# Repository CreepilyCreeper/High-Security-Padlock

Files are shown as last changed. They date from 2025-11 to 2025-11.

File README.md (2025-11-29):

# High-Security Padlock Design (EN 12320 Grade 5)

**Project Status:** Completed (Academic Design & Analysis)
**Tools Used:** SolidWorks

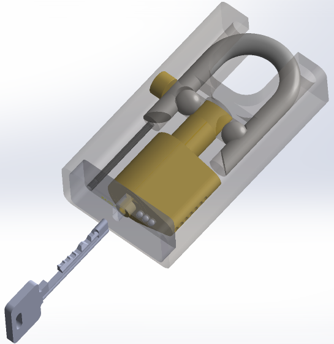
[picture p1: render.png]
Main Render


*(Final assembly render of the modified Bowley-style padlock)*

Animation

*(Animation of padlock mechanism)*

## Abstract
This project involves the design and analysis of a high-security padlock engineered to meet **EN 12320 Grade 5** standards. The design replaces conventional brass bodies with **AISI 304 Steel** and incorporates **Hardened Boron Steel** for the shackle (UTS > 1600 MPa). 

The primary innovation is a modified Bowley-style locking mechanism that shields pin access, rendering traditional lockpicking tools (raking/single-pin picking) ineffective.

## Technical Specifications

| Feature | Specification |
| :--- | :--- |
| **Shackle Material** | Hardened 1.5510 Boron Steel (UTS ≥ 1600 MPa) |
| **Body Material** | AISI 304 Stainless Steel (Machined) |
| **Locking Mechanism** | 7-Pin Modified Bowley System (Shielded Keyway) |
| **Anti-Drill** | Embedded 52100 Chrome Steel Bearings |
| **Key Differs** | > 16,000 combinations ($4^7$) |
| **Est. Production** | CNC Milling & Turning (ISO 286 Grade 8 Tolerances) |

## Engineering Analysis (FEA)

### 1. Shackle Tensile & Torsion Test
Finite Element Analysis verified the shackle withstands tensile forces exceeding **70 kN** and torsion forces exceeding **1200 Nm**.

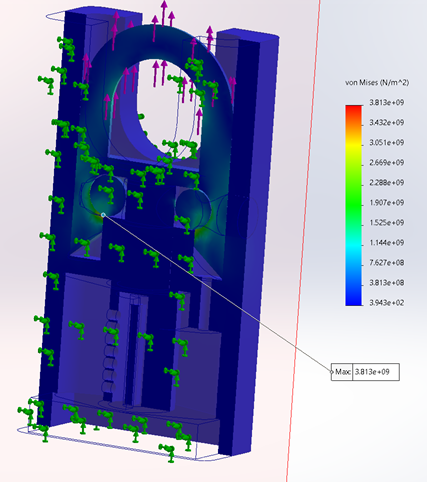
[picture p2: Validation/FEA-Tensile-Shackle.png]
FEA Shackle Tensile
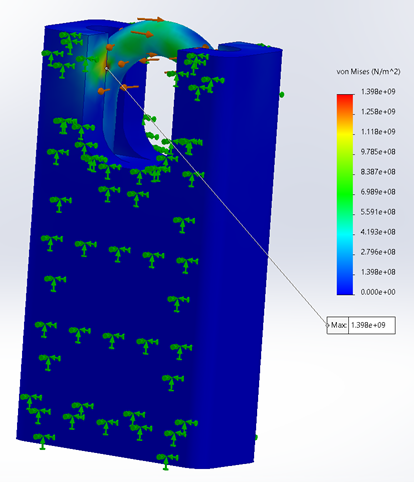
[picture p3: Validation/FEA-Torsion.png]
FEA Shackle Torsion
 

### 2. Mechanism Stress Analysis
Calculations on the internal locking pins and Finite ELement Analysis on the lock pin and base plate confirm the lock mechanism's resistance to **10 kN** pulling force and **20 Nm** torque, ensuring the mechanism does not shear under forced entry attempts.

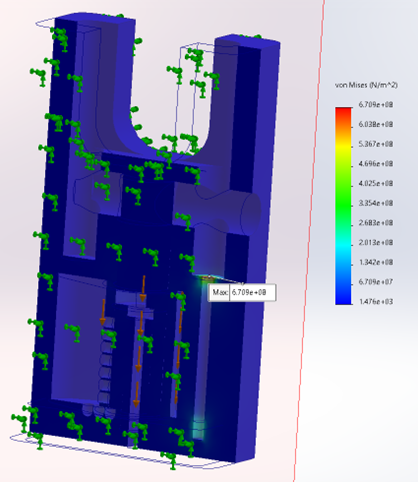
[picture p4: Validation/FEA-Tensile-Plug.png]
FEA Plug Tensile


## ⚙️ Design for Manufacturing (DFM)
*   **Machining vs. Casting:** Selected CNC machining for the steel body to ensure tighter tolerances (10 microns) required for the shielded keyway mechanism.
*   **Assembly:** Optimized for manual assembly with a "stacking" design, utilizing clearance fits for internal components and limited press-fits for sealing, reducing the need for complex adhesives or welding.

## 📂 Project Files
*   [Full Engineering Report (PDF)](./Documents/High_Security_Padlock_Report.pdf)
*   [CAD](./CAD+Manufacturing/) [Drawing](./Documents/Padlock%20Assembly.pdf)

---
*Created by Samuel Leung for MECH2520 Final Project*

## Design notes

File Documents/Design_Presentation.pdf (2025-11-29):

# Design Considerations of High Security Padlock

# LEUNG Hei Tzit Samuel (21051167)

# Motivation

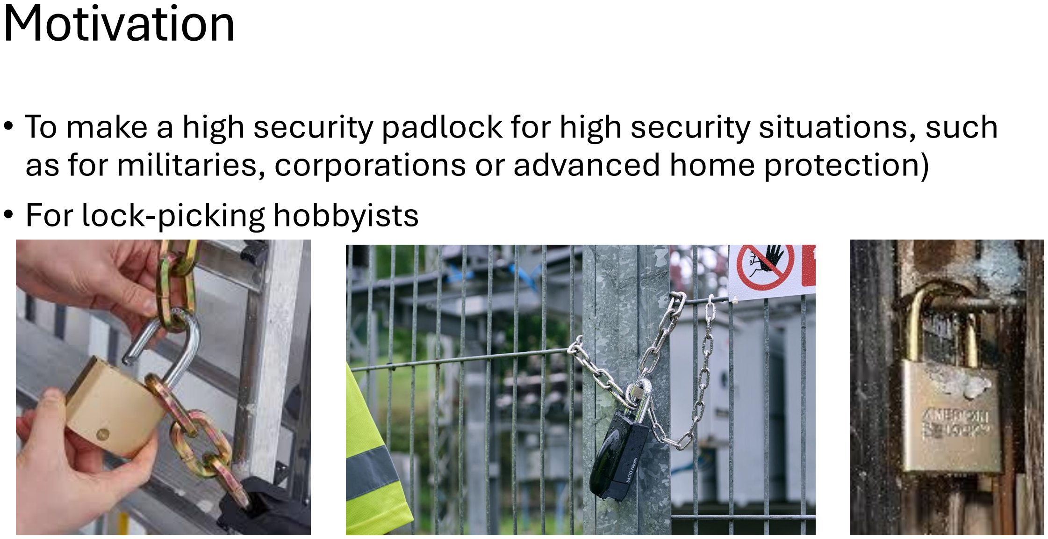
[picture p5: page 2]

# - To make a high security padlock for high security situations, such as for militaries, corporations or advanced home protection) - For lock-picking hobbyists

# Functional Specifications

1. The padlock should be able to open and close its shackle.

# 2. The padlock should be able to be fit onto an object of normal size when

locked, such as handles, latches, hoops and chain links.

# 3. The padlock should only be operable when in ownership of a key/unlocking

device.

# 4. The padlock should be able to withstand unauthorized intrusion, such as:

# Picking/Decoding, Drilling, Cutting/Sawing, Pulling, Heavy and/or Repeated Impact, etc

# 5. The padlock should be able to withstand repeated use and environmental-

related wear, such as weather, temperature and corrosion.

# 6. The padlock should be minimized to be affordable enough for consumers

more concerned with security, such as corporations or businesses.
7. The padlock should be able to be certified as CEN Grade 5.

# Engineering Specifications

## 1. Minimum Number Of Key Differs: 10000 (from CEN EN12320 Grade 5) 2. Resistance to Pulling Of Shackle: ≥ 70 kN (from CEN EN12320 Grade 5) 3. Resistance to Twisting Of Shackle: ≥ 1200 Nm (from CEN EN12320 Grade 5) 4. Resistance to Cutting of Shackle: ≥ 70 kN (from CEN EN12320 Grade 5)

5. Low Temperature Resistance to Impact on Shackle: −40℃, 6550 g, 1400 mm ≥ 5 times (from CEN EN12320 Grade 5)
6. Low Temperature Resistance to Impact on Lock Body: −40℃, 6550 g, 1400 mm ≥ 5 times (from CEN EN12320 Grade 5)

7. Resistance to Force on Locking Mechanism: ≥ 10 kN (from CEN EN12320 Grade 5) 8. Resistance to Torque on Locking Mechanism: ≥ 20 Nm (from CEN EN12320 Grade 5) 9. Time taken to Drill through Lock: ≥ 4 Minutes (from CEN EN12320 Grade 5) 10. Time taken to Saw through Lock: ≥ 4 Minutes (from CEN EN12320 Grade 5) 11.Lifetime: ≥ 10 Years (Point 5) 12.Cannot insert normal lock pick

# Calculations from Engineering Specifications

- Though modelling the key elements of padlock design and using FEA, the key stress zones of the design

were found to be on the shackle. Comparing with solutions found in the industry and these calculations, hardened high strength steel was chosen for the shackle. EN 1.5510+H Boron Steel or 17-4 PH Stainless Steel are potential candidates for the shackle as they both have a UTS of above 1.3GPa, which allows for the system to withstand above 70kN of pulling force on the shackle once, as specified

in the CEN grading requirements.

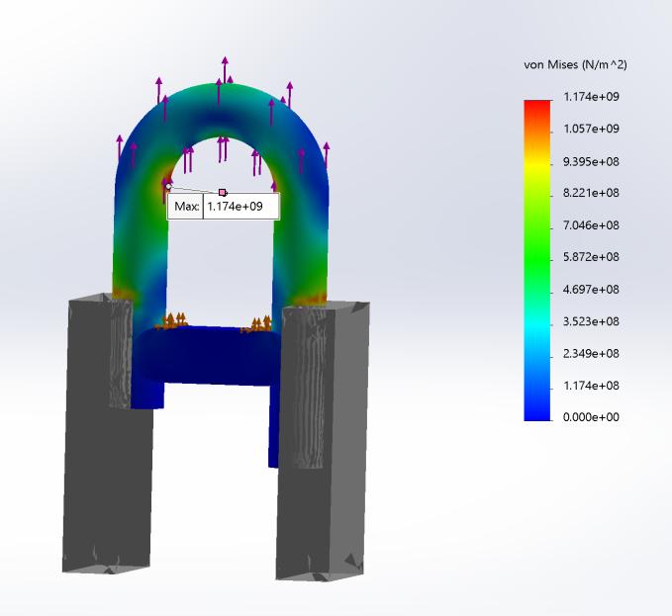
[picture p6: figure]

## - The number of pins was calculated though the assumption of having 4

height settings for each pin.

## Total Combinations = 4

## 7 = 16384 ≥ 10000 combinations

Thus 7 pins will be used.

- Though modelling the key elements of padlock design and using FEA, the key stress zones of the design

were found to be on the shackle. Comparing with solutions found in the industry and these calculations, hardened high strength steel was chosen for the shackle. EN 1.5510+H Boron Steel or 17-4 PH Stainless Steel are potential candidates for the shackle as they both have a UTS of above 1.3GPa, which allows for the system to withstand above 70kN of pulling force on the shackle once, as specified

in the CEN grading requirements.

## - The number of pins was calculated though the assumption of having 4

height settings for each pin.

## Total Combinations = 4

## 7 = 16384 ≥ 10000 combinations

Thus 7 pins will be used.

# Assembly Drawing

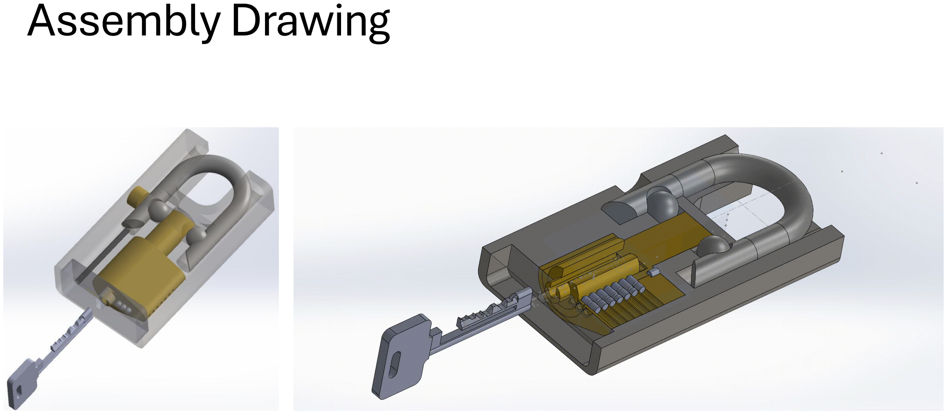
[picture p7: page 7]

# Design Choices

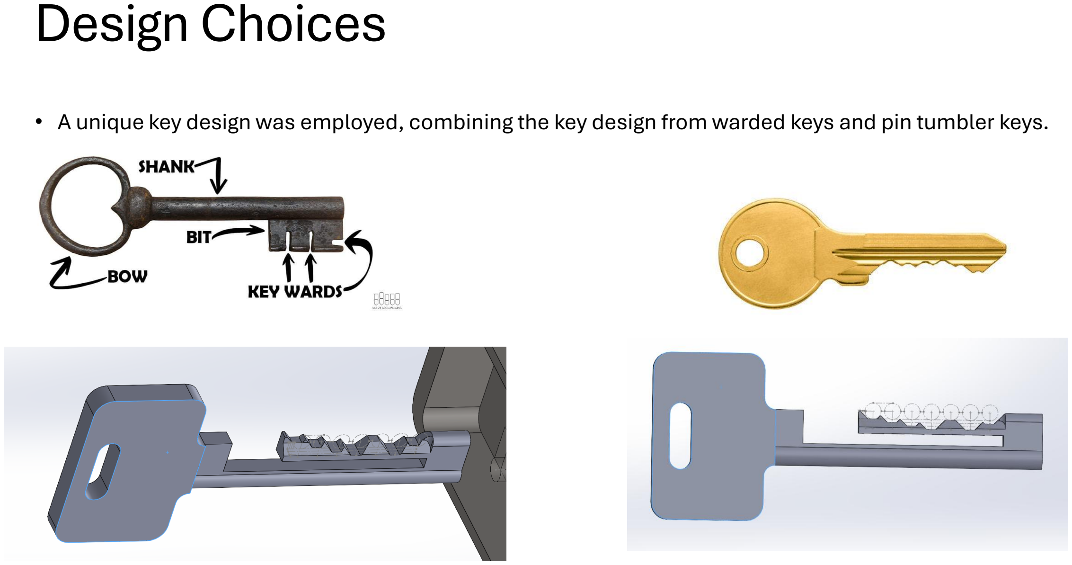
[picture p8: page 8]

- A unique key design was employed, combining the key design from warded keys and pin tumbler keys.

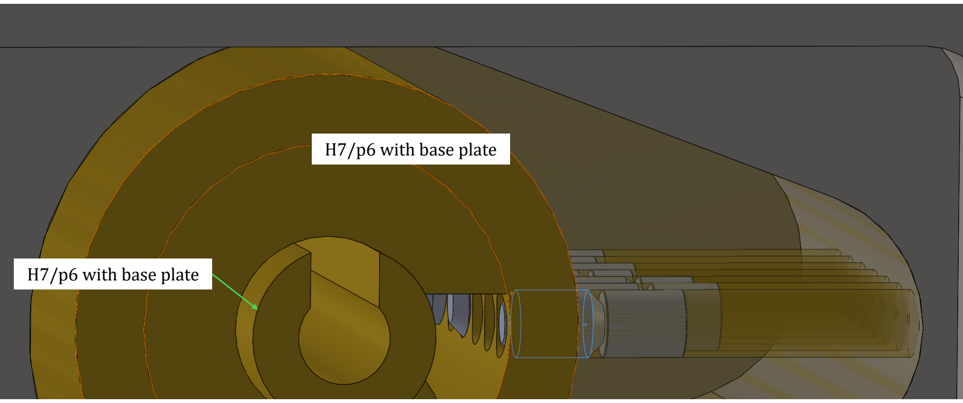
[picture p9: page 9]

## H7/p6 with base plate

## H7/p6 with base plate

# Verification of design: FEA

Shackle Pulling Test | Shackle Twisting Test | Plug Pulling Test

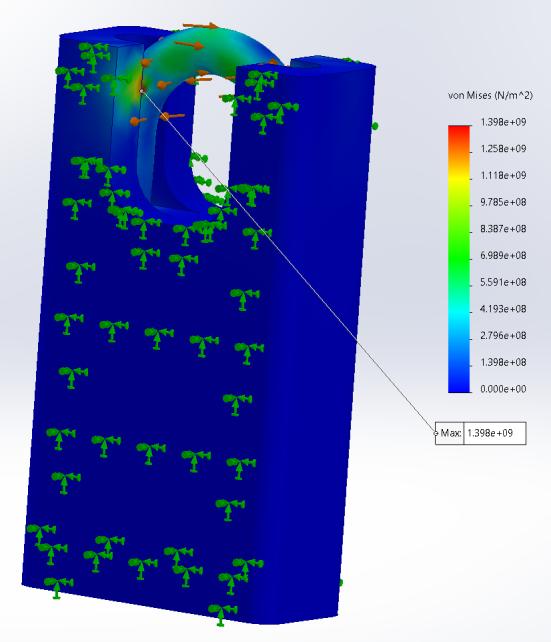
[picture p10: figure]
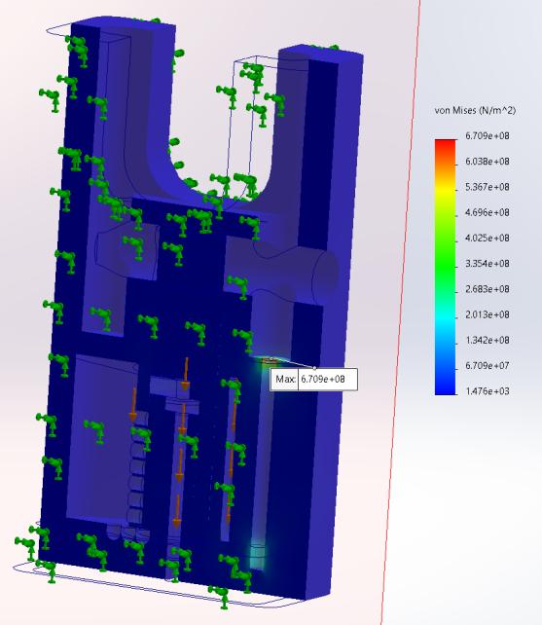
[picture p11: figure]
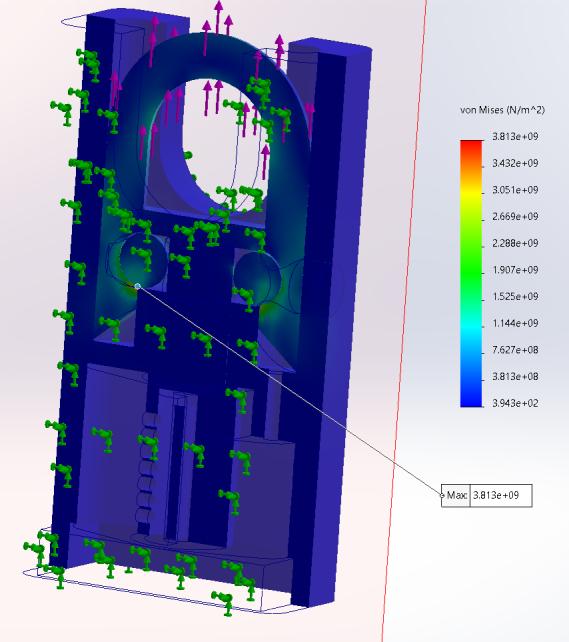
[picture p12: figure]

# Verification of design: Calculation

# Shackle Cutting Resistance

Material Properties

- Steel Grade: 1.5510 (Chromium-Tungsten Tool Steel)
- Ultimate Tensile Strength (UTS): 1600 MPa (from material data)
- Estimated Shear Strength (τ\tau):

τ ≈ 0.6 ∗ UTS = 960 MPa

For full-section shear (assuming bolt cutter jaws fully engage the shackle):

A = π × d

2 = π × (10 mm)

2≈ 314.16 mm²

Using the shear equation:

Fs = τ × A = 960 MPa × 314.16 mm² ≈ 301.6 kN

# Plug Twisting Resistance

Material Properties

- Steel Grade: Brass
- Ultimate Tensile Strength (UTS): 480 MPa (from material data)
- Estimated Shear Strength (τ\tau):

τ ≈ 0.6 ∗ UTS = 288 MPa

For full-section shear (assuming bolt cutter jaws fully engage the shackle):

A = π × d

2 × n = π × (2.921 mm)

2 × 7 ≈ 187.63 mm²

Using the shear equation:

Fs = τ × A = 288 MPa × 187.63 mm² ≈ 54 kN

τplug = Fs × rplug = 54 × 11 mm = 594 Nm

# Access Prevention Measures

# - The pins are shielded away from the keyhole, meaning typical/standard

lockpicks and rakes cannot access the pins.

# - The design provides little room for bumping due to having no room for the key to shift in and out of the lock when engaging with the pins, enforceable with

decent tolerances.

# - Hardened steel plates and ball bearings are placed in key locations such as near the shear line, pins and securing bolt, vastly increasing the difficulty of

drilling though the padlock.

# - The shackle penetrates deep into the lock body, increasing the difficulty of

breaking the lock open using the double wrench method.

# - A closed shackle design forces intruders to cut 2 times before being able to access the contents

# Bill of Materials

ITEM NO. | COMPONENT NAME | DESCRIPTION | QTY.
1 | Shackle | Held by #2 | 1
2 | 12mm Diameter Bearing Ball | Part of the latching mechanism, Loose fit, Purchased from supplier: https://simplybearings.co.uk/shop/p35948/12mm-
Diameter- (https://simplybearings.co.uk/shop/p35948/12mm-Diameter-Grade-100-Hardened-52100-Chrome-Steel-Ball-Bearings/product_info.html)Grade- (https://simplybearings.co.uk/shop/p35948/12mm-Diameter-Grade-100-Hardened-52100-Chrome-Steel-Ball-Bearings/product_info.html)100- (https://simplybearings.co.uk/shop/p35948/12mm-Diameter-Grade-100-Hardened-52100-Chrome-Steel-Ball-Bearings/product_info.html)Hardened- (https://simplybearings.co.uk/shop/p35948/12mm-Diameter-Grade-100-Hardened-52100-Chrome-Steel-Ball-Bearings/product_info.html)52100- (https://simplybearings.co.uk/shop/p35948/12mm-Diameter-Grade-100-Hardened-52100-Chrome-Steel-Ball-Bearings/product_info.html)Chrome- (https://simplybearings.co.uk/shop/p35948/12mm-Diameter-Grade-100-Hardened-52100-Chrome-Steel-Ball-Bearings/product_info.html)Steel- (https://simplybearings.co.uk/shop/p35948/12mm-Diameter-Grade-100-Hardened-52100-Chrome-Steel-Ball-Bearings/product_info.html)Ball- (https://simplybearings.co.uk/shop/p35948/12mm-Diameter-Grade-100-Hardened-52100-Chrome-Steel-Ball-Bearings/product_info.html)Bearings/product_info.html (https://simplybearings.co.uk/shop/p35948/12mm-Diameter-Grade-100-Hardened-52100-Chrome-Steel-Ball-Bearings/product_info.html) | 2
3 | Lock Plug Body | Engages with the rest of the lock plug and the latching mechanism | 1
4 | Key Limiter | Blocks unauthorized access to pins, Press fitted onto base plate | 1
5 | Lock Plug Shell | Holds pins and rest of lock plug in place, Interference fit | 1
6 | Lock Plug Key Holder | Holds key in plug, Loose fitting | 1
7 0.115D Kwikset B1 0.172H | | Purchased from supplier: https://www.uhs-hardware.com/products/lab-lmdkwk-mini-dur-x-kwikset-rekeying-kit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 LhZmbID8cBJCDeKrGQW6kP- (https://www.uhs-hardware.com/products/lab-lmdkwk-mini-dur-x-kwikset-rekeying-kit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)Sqc710dRzmEcgdC4 (https://www.uhs-hardware.com/products/lab-lmdkwk-mini-dur-x-kwikset-rekeying-kit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) Clearance fit into #6 | 2
8 | 0.115D Kwikset B2 0.195H | | 2
9 | 0.115D Kwikset B3 0.218H | | 1
10 | 0.115D Kwikset B4 0.241H | | 2
11 | 0.115D Kwikset M6 0.138H | | 2
12 | 0.115D Kwikset M5 0.115H | | 2
13 | 0.115D Kwikset M4 0.092H | | 1
14 | 0.115D Kwikset M3 0.069H | | 2
15 | 0.115D Kwikset T1 0.16H | | 8
16 | 0.115D Kwikset Spring | | 7
17 | Base Plate | Steel plate to prevent drilling attacks against the base of the padlock | 1
18 | Key | | 1
19 | 3mm Diameter Bearing Ball | Anti-Drill protection, Purchased from supplier: https://simplybearings.co.uk/shop/p35912/3mm-Diameter-Grade-100-
Hardened- (https://simplybearings.co.uk/shop/p35912/3mm-Diameter-Grade-100-Hardened-52100-Chrome-Steel-Ball-Bearings/product_info.html)52100- (https://simplybearings.co.uk/shop/p35912/3mm-Diameter-Grade-100-Hardened-52100-Chrome-Steel-Ball-Bearings/product_info.html)Chrome- (https://simplybearings.co.uk/shop/p35912/3mm-Diameter-Grade-100-Hardened-52100-Chrome-Steel-Ball-Bearings/product_info.html)Steel- (https://simplybearings.co.uk/shop/p35912/3mm-Diameter-Grade-100-Hardened-52100-Chrome-Steel-Ball-Bearings/product_info.html)Ball- (https://simplybearings.co.uk/shop/p35912/3mm-Diameter-Grade-100-Hardened-52100-Chrome-Steel-Ball-Bearings/product_info.html)Bearings/product_info.html (https://simplybearings.co.uk/shop/p35912/3mm-Diameter-Grade-100-Hardened-52100-Chrome-Steel-Ball-Bearings/product_info.html) , Clearance fit into #17 | 3
20 | Lock Body | | 1
21 | Press Fit Plug | Seals hole on #20 from milling out space for latching mechanism, Press fitted onto #20 | 1
22 | M4 45mm Machine screw | Purchased from supplier: https://sg.misumi-ec.com/vona2/mech_screw/M3301000000/M3301050000/M3301050200/Attaches #17 onto #20 | 1

# Summary

# - To conclude, the High Security Padlock provides a strong security

package for users to protect their valuables, facilities, homes, etc.

# - The specifications are all fulfilled and exceeded, allowing this padlock to be certified as CEN EN12320 Grade 5 or above after

lab testing.

# - The manufacturability of parts is high and many standards parts

are used.

# - The padlock should be suitable for those concerned with their security, and should give lockpicking enthusiasts a decent

challenge.

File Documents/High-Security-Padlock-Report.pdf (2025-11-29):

## High Security Padlock Design

Hei Tzit Samuel LEUNG (Email: htsleung@connect.ust.hk, Student ID: 21051167)

Abstract
This report presents the design of a high-security padlock featuring a unique locking mechanism to prevent lockpicking and advanced anti-drill protection. The lock body is constructed from steel rather than brass, with integrated ball bearings enhancing security. Machining was chosen over alternative manufacturing methods to ensure tighter tolerances at a competitive cost. The design meets the stringent requirements for EN 12320 certification at Grade 5. Key design motivations, specifications, and manufacturing considerations are discussed, highlighting contributions to security innovation.

### 1. Design Motivations

Security breaches due to lockpicking and drilling pose significant risks in governmental, commercial and residential applications. Conventional locks often rely on brass bodies and standard locking mechanisms, which can be exploited by skilled attackers. This design addresses these weaknesses through a precision-engineered mechanism that resists manipulation and direct force attacks. By adopting an alternative locking mechanism and anti-drill elements, the padlock ensures improved security while maintaining reliability, longevity and cost-competitveness, making it ideal for high-security environments such as industrial facilities, corporate storage units, warehouses, and government sites.

### 2. Reference Parts and Design Contributions

2.1. Reference Parts and Industrial Solutions
Existing high-security padlocks focus on resisting physical attacks such as drilling or wrenching, rather than security in their locking mechanism. Most, if not all of these locks employ standard pin tumblers or disc detainers. While effective to an extent, these designs remain extremely vulnerable to picking techniques such as raking and single-pin/disk manipulation, allowing unauthorized access in the tens of seconds.
There have been solutions proposed by other companies, such as the chain key padlock [1] and the Bowley lock [2] (which influenced my design greatly), with all designs balancing between difficulty, reliability and cost to manufacture.
2.2. Difference and Incremental Contribution of Proposed Design
This padlock differentiates itself from traditional high-security padlocks by integrating an innovative locking mechanism designed to prevent all traditional lockpicking methods from succeeding without specially designed tools. The locking mechanism was heavily inspired by the Bowley lock’s design of shielding away access to unlocking pins, with modifications to provide additional security to attacks such as raking and bumping, through modifying how the key engages with the locking pins. This design also provides a smoother unlocking sequence which provides users with ease of use. Additionally, the embedded steel bearings at key areas provide higher drilling resistance at a reasonable cost, ensuring security at a higher level than conventional designs.

### 3. Design Specifications

3.1. Functional Specifications of Proposed Design
- Locking Mechanism:
- Security: Prevents insertion of typical lockpick or rake.
- Ease of Use: Provides unlocking and locking through only a 180° rotation
- Lifetime: corrosion and rust resistant, a lifetime of at least 20 years.

- Security Certification: Designed to meet EN 12320 Grade 5 standards.
- Minimum Number Of Key Differs: 10000
- Resistance to Pulling Of Shackle: ≥70 kN
- Resistance to Twisting Of Shackle: ≥1200 Nm
- Resistance to Cutting of Shackle: ≥70 kN
- Shackle and Body Resistance to Impact at Low Temperature: -40℃, Dropping a weight of 6550 g from 1400 mm ≥ 5 times each
- Resistance to Force on Locking Mechanism: ≥10 kN
- Resistance to Torque on Locking Mechanism: ≥20 Nm
- Time taken to Drill through Lock: ≥4 Minutes
- Time taken to Saw through Lock: ≥4 Minutes
3.2. Engineering Specifications of Proposed Design
- Shackle: Closed shackle, 10mm Diameter, Hardened steel with UTS ≥1370 MPa. Hardened 1.5510 Boron steel is proposed, with a maximum UTS of 1600 MPa after treatment, and a maximum Brinell Hardness of 190.
- Latching Mechanism: Dual ball bearing locking system. Balls are hardened.
- Locking Mechanism: Pin tumber, 7 pins, 4 levels on each pin, Brass.
- Body: Corrosion resistant steel, optional case hardening.
- Anti-Drill Mechanisms: 3 hardened ball bearings with 3mm diameter in front of shear line and pins.
3.2.1. Calculations for Specification Verification
i) Key Differs
Total Combinations = 4

7 = 16384 ≥ 10000 combinations. ii) Design of Shackle
For the tensile and torsional resistance of the shackle, an FEA analysis was done to find out the minimum UTS required of the shackle, as seen in Figure 1. According to analysis, the minimum UTS of the shackle material must reach 1.37 GPa.

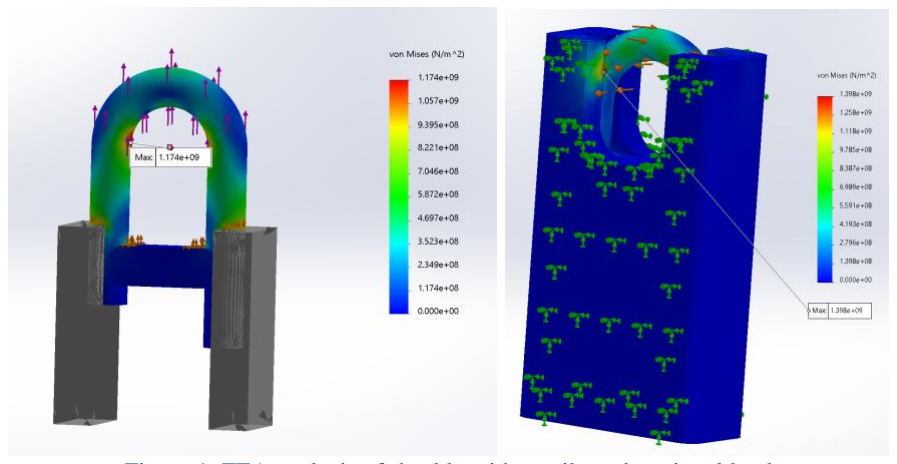
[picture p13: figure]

Figure 1: FEA analysis of shackle with tensile and torsional load

The cutting resistance was calculated by estimating the shear strength from UTS by multiplying by a factor of 0.6 (UTS was assumed to be 1200 MPa in the calculations below):
τ ≈ 0.6 × UTS = 0.6 × 1200 MPa = 720 MPa For full-section shear (assuming bolt cutter jaws fully engage the shackle):
A = π × d

2 = π × (10 mm)

2 ≈ 314.16 mm²

Using the shear equation:
Fs = τ × A = 720 MPa × 314.16 mm² ≈ 226.2 kN

Which far exceeds the 70 kN cutting resistance requirement.

iii) Design of Locking Mechanism
For the pulling resistance of the locking mechanism, an FEA analysis was done to find out the load on the bottom plate, as seen in Figure 2. According to analysis, the minimum UTS of the shackle material must reach 1.37 GPa. The load concentrated the most on the screw, which had a maximum of 670 MPa on the screw head hole. It should be noted that this value is overestimated by the FEA simulation, as the forces would be distributed along the screw threads instead of concentrating on the screw head, which were not included in the FEA simulation due to complications in computation. The stress would most likely reach a maximum of about 210 MPa near the bottom of the screw hole.

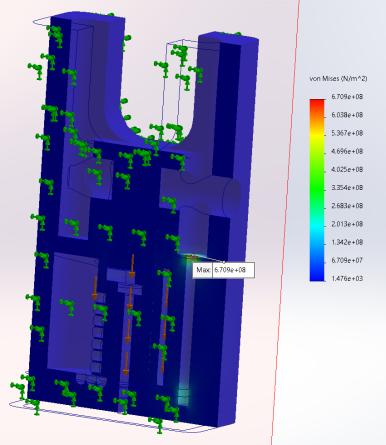
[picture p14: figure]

Figure 2: FEA analysis of locking mechanism when pulled

The resistance to torque on the locking mechanism is concentrated on the 7 locking pins along the shearing line of the locking mechanism. The total shearing resistance of the pins were calculated by estimating the shear strength from UTS by multiplying by a factor of 0.6 (UTS was assumed to be 480 MPa, which is the typical UTS of brass):
τ ≈ 0.6 ∗ UTS = 288 MPa
For full-section shear:
A = π × d

2 × n = π × (2.921 mm)

2 × 7 ≈ 187.63 mm²

Using the shear equation:
Fs = τ × A = 288 MPa × 187.63 mm² ≈ 54 kN τplug = Fs × rplug = 54 × 11 mm = 594 Nm

Which far exceeds the 20 Nm cutting resistance requirement.

Given the hardness of steel (Brinell Hardness 200+), calculations confirm the resistance to drilling compared to brass (Brinell Hardness ~90). The lock mechanism tolerances are within 10 microns, ensuring high precision and smooth operation.

### 4. Detailed Design Considerations

Manufacturing Methods:
To achieve high precision and durability, machining was selected over other methods such as casting, electrical discharge machining (EDM), or sintering. Machining allows for tight tolerances, ensuring that the lock components fit precisely without defects that might compromise security. The CNC milling and turning process ensures the steel body and internal components retain their structural integrity, reducing the likelihood of mechanical failure. EDM is able to produce the tolerances required by the design, at the expense of a much lower production rate, thus machining was chosen over EDM. Casting the lock body is possible, but at the expense of introducing casting to an otherwise machining only production line, which may be uneconomical depending on the scale of production. On the other hand, casting the steel body would circumvent the difficulties in machining 304 steel.
Materials Used:
Lock Body: Hardened AISI 304 steel, chosen for its hardness, resistance towards drilling and corrosion resistance. The material cost was a large factor in deciding between types of steel, as the body is quite large. The corrosion resistance was also important, as the body had to resist corrosion from outside environments.
Locking Mechanism Components: Brass, due to its low cost, corrosion resistance and ease in machining, which is the main concern due to the higher complexity of these parts.
Ball bearings: 52100 Chrome Steel Ball bearings, or other similar hardened ball bearings on the market, for their resistance to drilling and strength, which are required for the latching mechanism and anti-drilling measures to remain secure.
Optimizations for Assembly, Manufacturing, and Cost:
Many parts are sourced from the market, such as the screw, ball bearings, lock pins and lock springs. Optimization was done to reduce part count and machining complexity, which reduces machining time, assembly time and cost while improving reliability. Parts had their geometries rounded and simplified, such as the lock plug and key, to enable easier machining.
Assembly is kept as simple as possible, with assembly mostly consisting of stacking clearance fit parts, inserting loose pins, 2 press fit parts and 1 bolt. The locking mechanism requires stacking in only 1 direction, which allows for easy manual assembly of parts. Only 2 parts are press fit, which removes the need for other binding materials. The assembly process would most likely be done by hand at a single workstation, as the market demand does not justify the cost of setting up an automated assembly process. The size of each part, although small, allow for ease in human handling.
Mathematical & Kinematic Analysis:
Special care was placed on the engagement of the pins and the key, which is vital to smooth and wear-free operation. A curve was cut into the locking mechanism to ensure a consistent 45° surface to engage with the pins when lowering the pins to engage with the key when unlocking (see Figure 3).

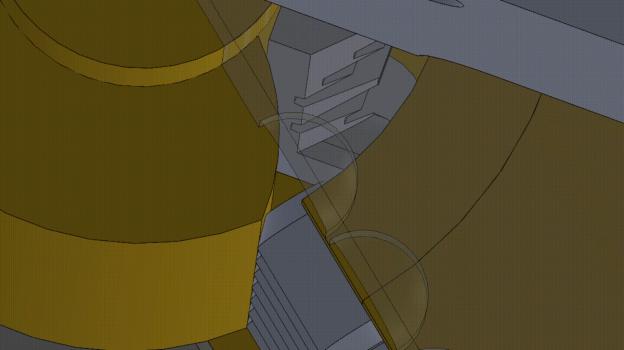
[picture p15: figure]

Figure 3: Animation of unlocking mechanism

The components in the lock components each have a clearance fit to the next one, with tolerances at ISO 286 Grade 8 for each component, or as specified below:

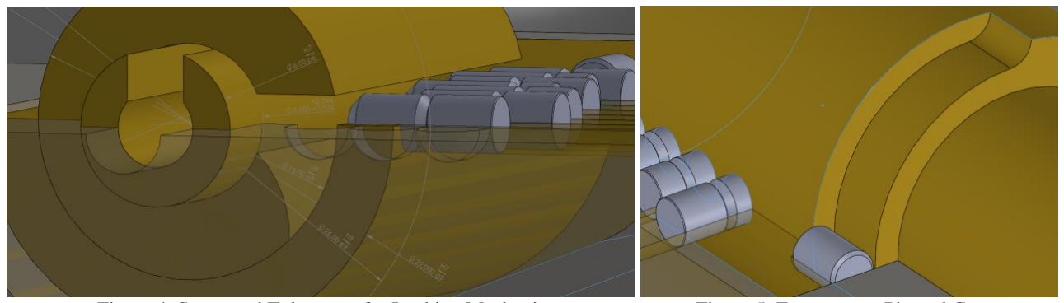
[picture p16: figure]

Figure 4: Suggested Tolerances for Locking Mechanism | Figure 5: Engagement Pin and Groove

The free spinning of the lock components are restricted by pins and grooves placed in the lock drum as seen in Figure 5 to ensure the proper engagement between the key, latching mechanism and other components.

### 4. Reviewer’s Comments

4.1. Reviewer 1 (Jacky SUEN, student)
The design should consider whether the locking mechanism was manufacturable.
Design updates based on feedback: I modified the design to smoothen out corners in the key and the padlock to ensure manufacturability.
4.2. Reviewer 2 (Michal LEE, student)
The design should consider the assembly of the latching mechanism, with focus placed on drilling out the space required for the bearings to move.
Design updates based on feedback: I modified the design to include a hole on one side of the body, allowing the hole for the latching mechanism to be machined through drilling once. A press fit brass seal would seal the hole. Brass was chosen as intrusion through the press fit would have to pass through the hardened boron steel shackle before reaching the latch, which would be unfeasible for an attacker.
4.3. Reviewer 3 (Henrick CHAN, student)
The design should consider reducing the number of ball bearings as anti-drill replacements.
Design updates based on feedback: I modified the design from having 15 ball bearings to only 3, and localized them to key areas only.
The reviewers did not consent to the inclusion of their email in this report.

### 5. Conclusions

This high-security padlock design prioritizes resistance against lockpicking and drilling while maintaining cost-effective manufacturability. The reinforced shackle, steel body and anti-drill features ensure compliance with EN 12320 Grade 5 certification requirements. Ultimately, the design provides the customer with robust security, without sacrificing reliability nor affordability.

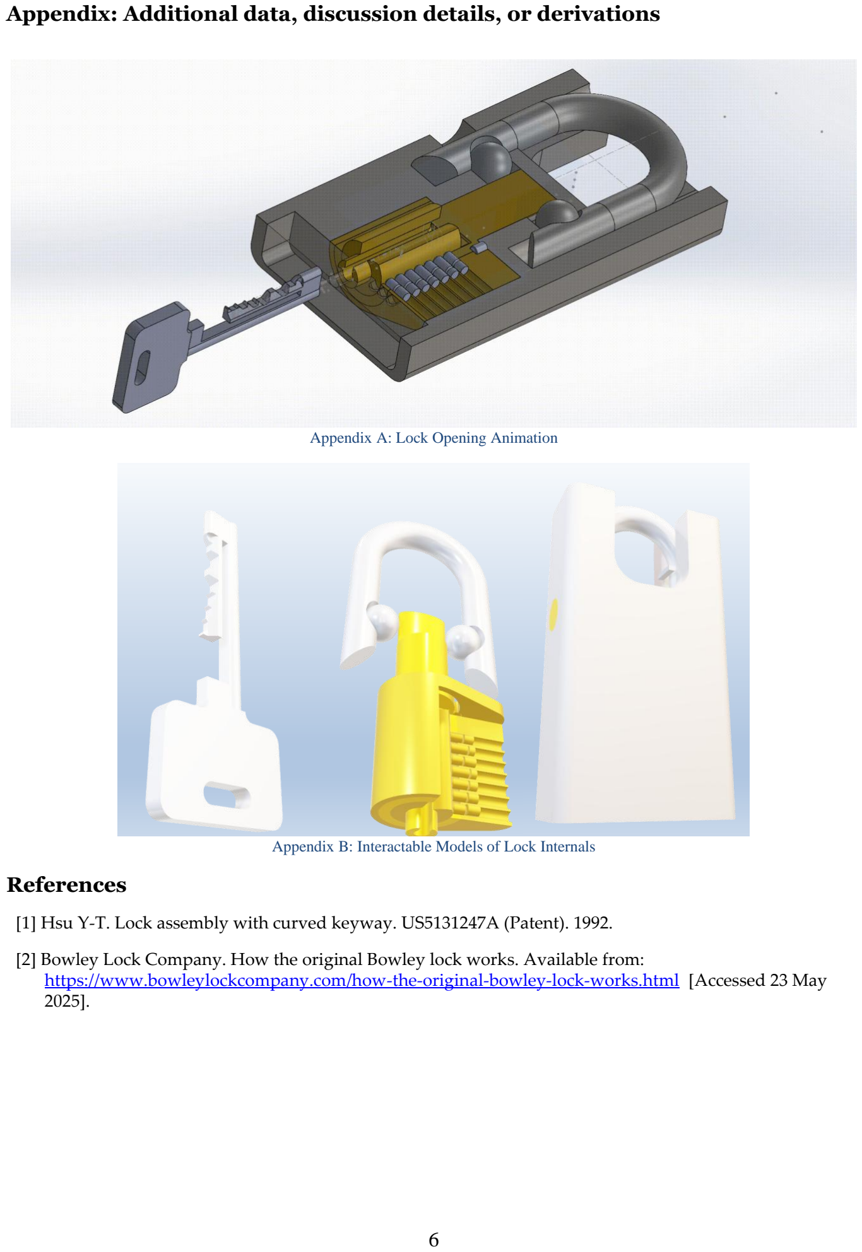
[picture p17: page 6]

Appendix: Additional data, discussion details, or derivations

Appendix A: Lock Opening Animation

Appendix B: Interactable Models of Lock Internals
References
[1] Hsu Y-T. Lock assembly with curved keyway. US5131247A (Patent). 1992.
[2] Bowley Lock Company. How the original Bowley lock works. Available from: https://www.bowleylockcompany.com/how-the-original-bowley-lock-works.html [Accessed 23 May 2025].

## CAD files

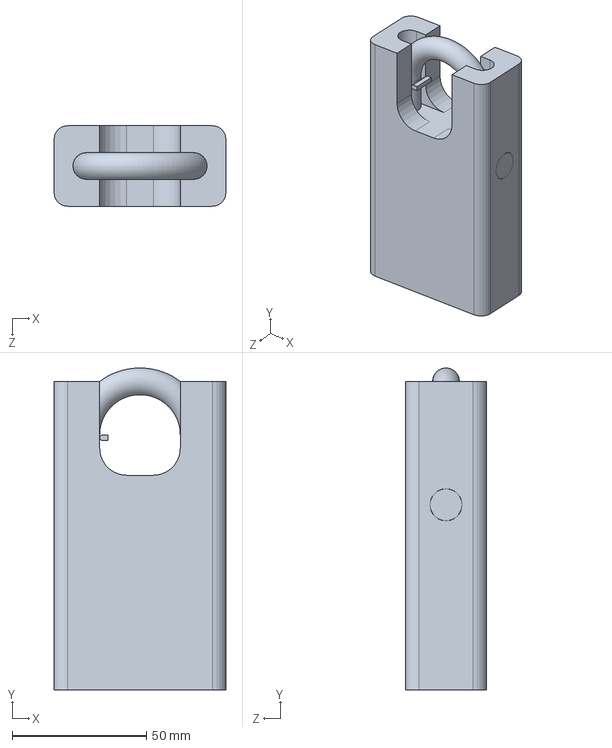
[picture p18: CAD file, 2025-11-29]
CAD/Padlock Assembly to be rendered.SLDPRT
64.0 x 120.0 x 30.0 mm

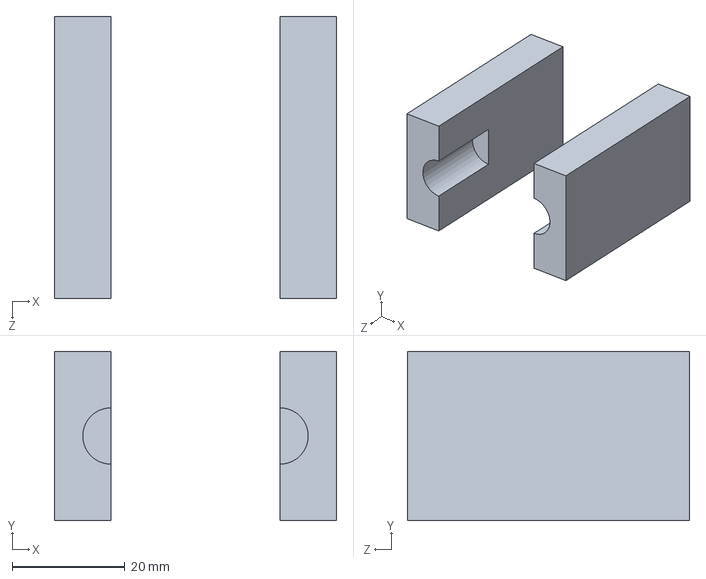
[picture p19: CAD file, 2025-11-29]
CAD/Static Testing Body.SLDPRT
50.0 x 30.0 x 50.0 mm

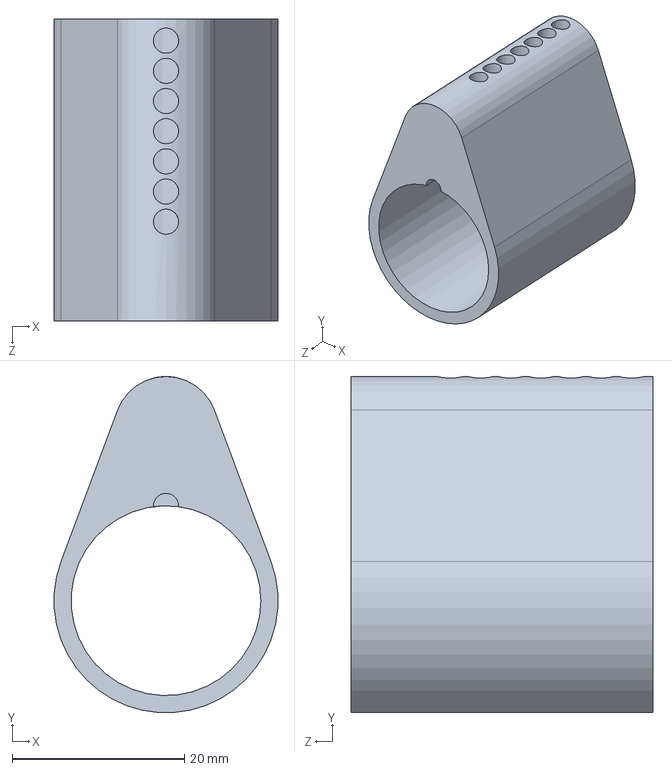
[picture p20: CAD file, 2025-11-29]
CAD/Plug_Body.SLDPRT
25.9 x 39.0 x 35.0 mm

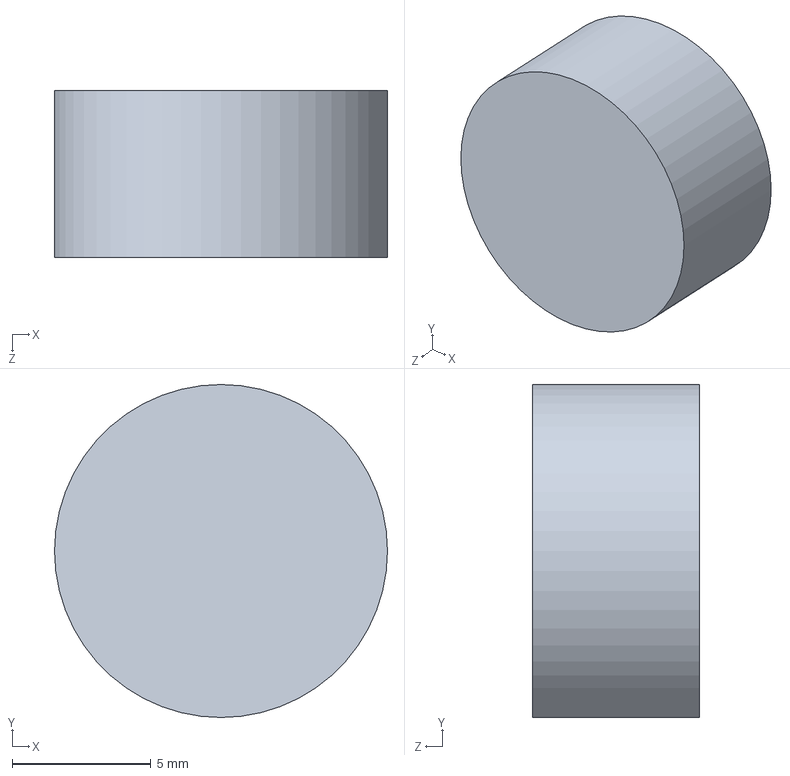
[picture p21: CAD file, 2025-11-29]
CAD/Press Fit Plug.SLDPRT
12.0 x 12.0 x 6.00 mm

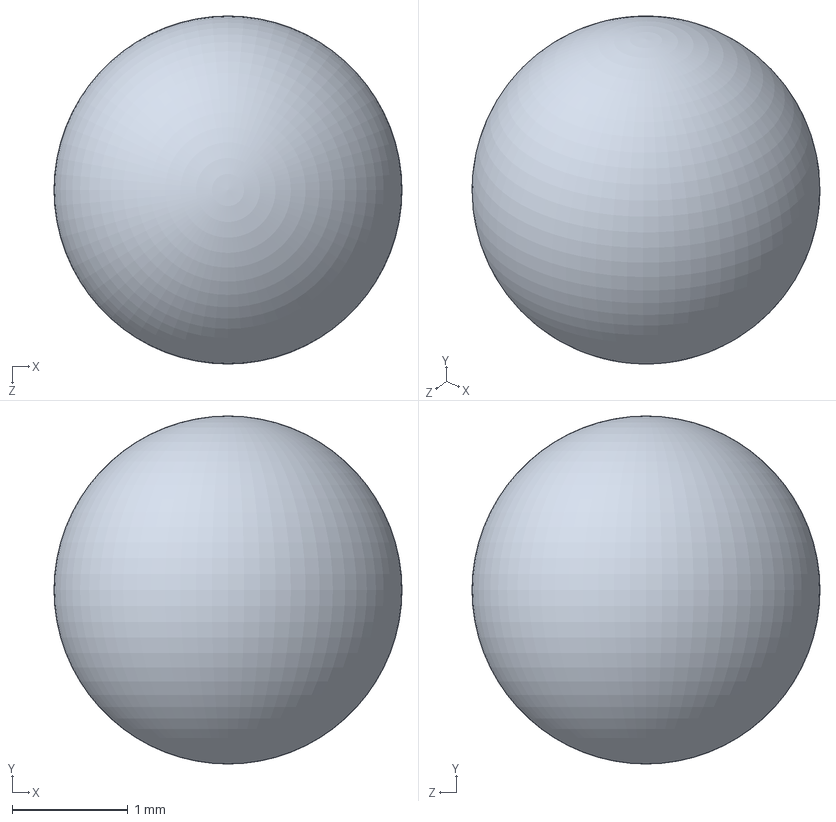
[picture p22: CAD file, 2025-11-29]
CAD/3mm Diameter Bearing.SLDPRT
3.00 x 3.00 x 3.00 mm

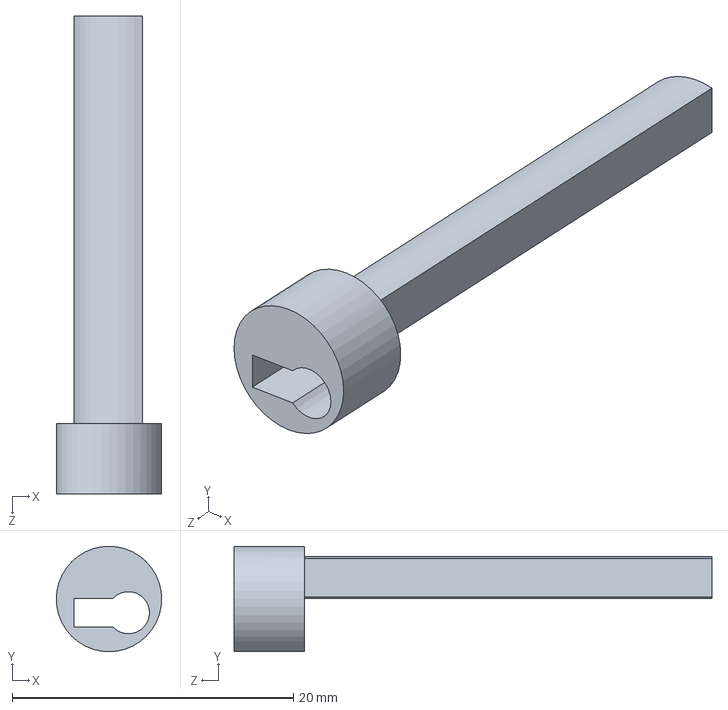
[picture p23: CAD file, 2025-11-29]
CAD/Key_Limiter_Press_Fit.SLDPRT
7.50 x 7.50 x 34.0 mm

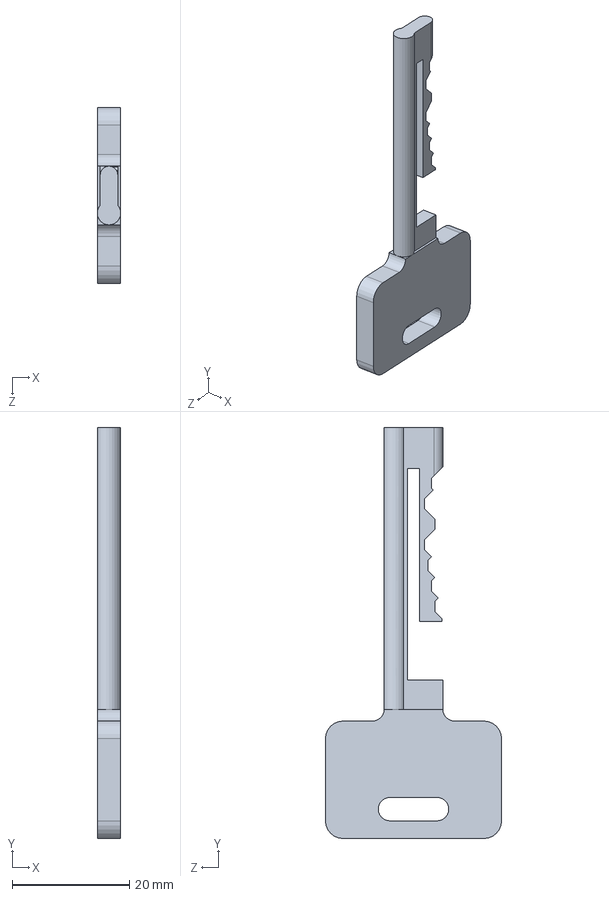
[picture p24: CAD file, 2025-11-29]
CAD/Key to be rendered.SLDPRT
4.00 x 70.0 x 30.0 mm

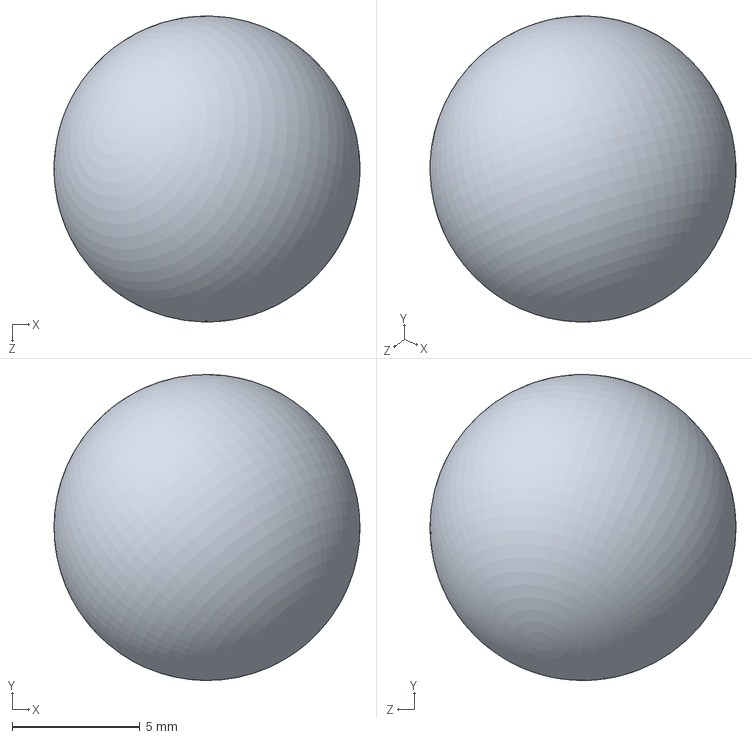
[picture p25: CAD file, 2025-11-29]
CAD/Latch Sphere.SLDPRT
12.0 x 12.0 x 12.0 mm

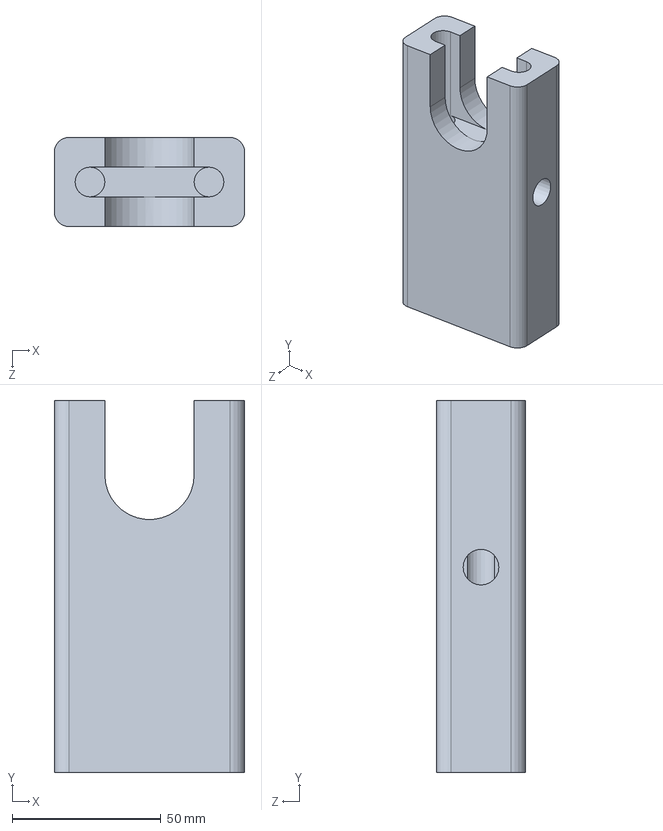
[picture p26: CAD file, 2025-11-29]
CAD/Lock Body.SLDPRT
64.0 x 125.0 x 30.0 mm

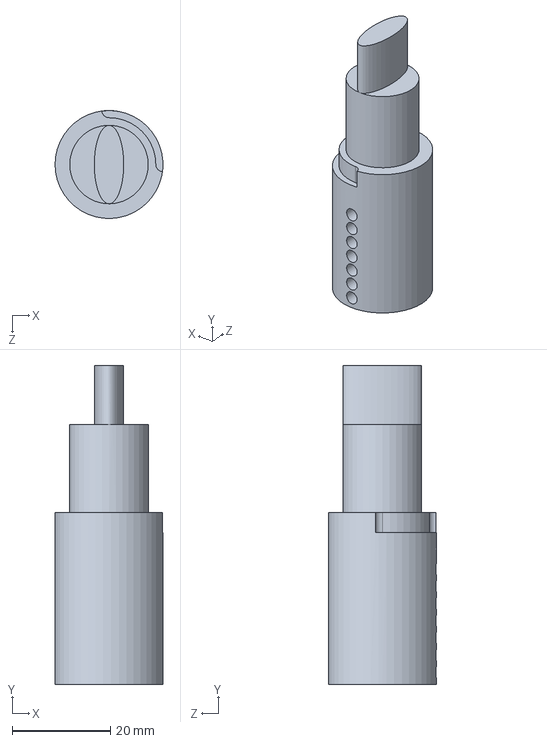
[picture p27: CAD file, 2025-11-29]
CAD/Lock_Drum-Keyway.SLDPRT
22.0 x 65.0 x 22.0 mm

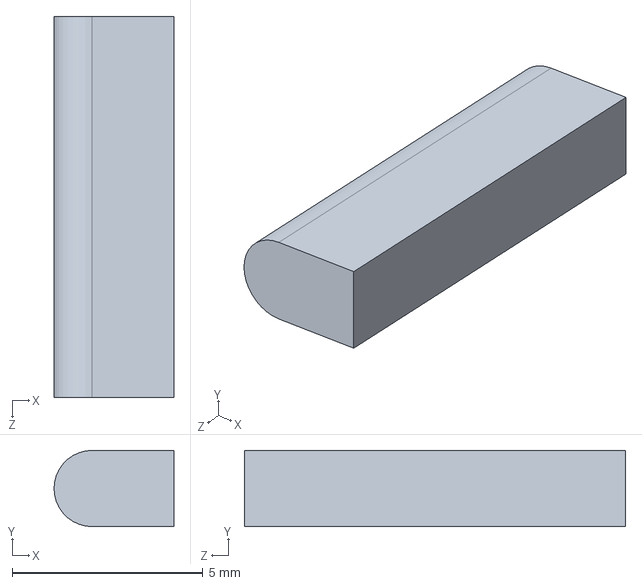
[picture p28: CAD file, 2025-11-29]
CAD/Blade.SLDPRT
3.15 x 2.00 x 10.0 mm

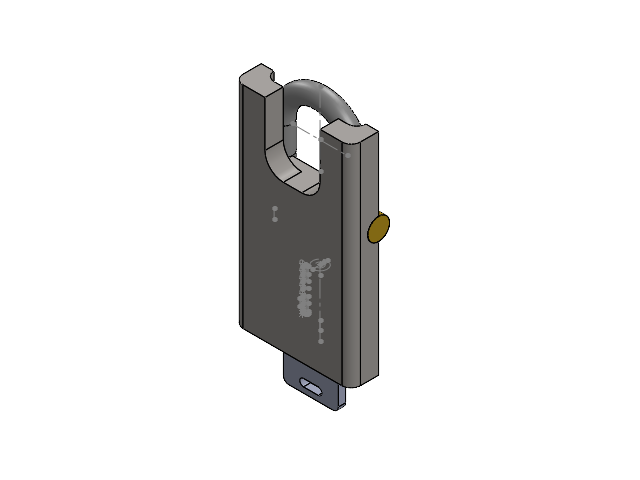
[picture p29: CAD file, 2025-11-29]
CAD/Padlock Motion.SLDASM
Lock Body
Base_Plate
Plug_Body
Lock_Drum-Keyway
Key_Limiter_Press_Fit
Key Hold
0.115D Kwikset T1 0.16H
Key
Shackle
Latch Sphere x 2
0.115D Kwikset B1 0.172H x 2
0.115D Kwikset B2 0.195H x 2
0.115D Kwikset B3 0.218H
0.115D Kwikset B4 0.241H x 2
0.115D Kwikset M3 0.069H x 2
0.115D Kwikset M4 0.092H
0.115D Kwikset M5 0.115H x 2
0.115D Kwikset M6 0.138H x 2
Press Fit Plug

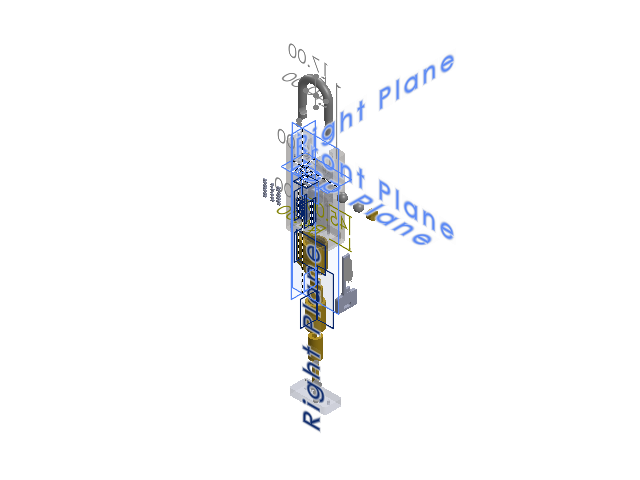
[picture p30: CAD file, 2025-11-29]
CAD/Padlock Assembly.SLDASM
Shackle
Latch Sphere x 2
Lock_Drum-Keyway
Key_Limiter_Press_Fit
Plug_Body
Key Hold
0.115D Kwikset B1 0.172H x 2
0.115D Kwikset B2 0.195H x 2
0.115D Kwikset B3 0.218H
0.115D Kwikset B4 0.241H x 2
0.115D Kwikset M6 0.138H x 2
0.115D Kwikset M5 0.115H x 2
0.115D Kwikset M4 0.092H
0.115D Kwikset M3 0.069H x 2
0.115D Kwikset T1 0.16H x 8
0.115D Kwikset Spring x 7
Base_Plate
Key
3mm Diameter Bearing x 3
Lock Body
Press Fit Plug
Blade x 2

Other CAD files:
CAD/Pin_Holding_Strip.SLDPRT
CAD/Base_Plate.SLDPRT
CAD/Key.SLDPRT
CAD/Latch Bar.SLDPRT
CAD/Base_Anti-Drill_Insert.SLDPRT
CAD/Key Hold.SLDPRT
CAD/Padlock Assembly.SLDDRW
CAD/Padlock Internals to be rendered.SLDPRT
CAD/Shackle.SLDPRT

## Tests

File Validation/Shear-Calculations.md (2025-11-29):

## Shackle Cutting Resistance

### Material Properties
- **Steel Grade:** 1.5510 (Chromium-Tungsten Tool Steel)
- **Ultimate Tensile Strength (UTS):** \( 1600 MPa \) (from material data)

### Shear Strength Calculation
- **Estimated Shear Strength (𝜏):**  
    \( 𝜏 ≈ 0.6 × UTS = 960 MPa \)

- **Sheared Area (A):**  
    \( A = \pi \times d^2 = \pi \times (10\, \text{mm})^2 \approx 314.16\, \text{mm}^2 \)

- **Shear Force (Fₛ):**  
    \( F_s = \tau \times A = 960\, \text{MPa} \times 314.16\, \text{mm}^2 \approx 301.6\, \text{kN} \)

---

## Plug Twisting Resistance

### Material Properties
- **Steel Grade:** Brass
- **Ultimate Tensile Strength (UTS):** \( 480 MPa \) (from material data)

### Shear Strength Calculation
- **Estimated Shear Strength (𝜏):**  
    \( 𝜏 ≈ 0.6 × UTS = 288 MPa \)

- **Sheared Area (A):**  
    \( A = \pi \times d^2 \times n = \pi \times (2.921\, \text{mm})^2 \times 7 \approx 187.63\, \text{mm}^2 \)

- **Shear Force (Fₛ):**  
    \( F_s = \tau \times A = 288\, \text{MPa} \times 187.63\, \text{mm}^2 \approx 54\, \text{kN} \)

- **Plug Shear Torque (𝜏ₚₗᵤg):**  
    \( \tau_{plug} = F_s \times r_{plug} = 54\, \text{kN} \times 11\, \text{mm} = 594\, \text{Nm} \)

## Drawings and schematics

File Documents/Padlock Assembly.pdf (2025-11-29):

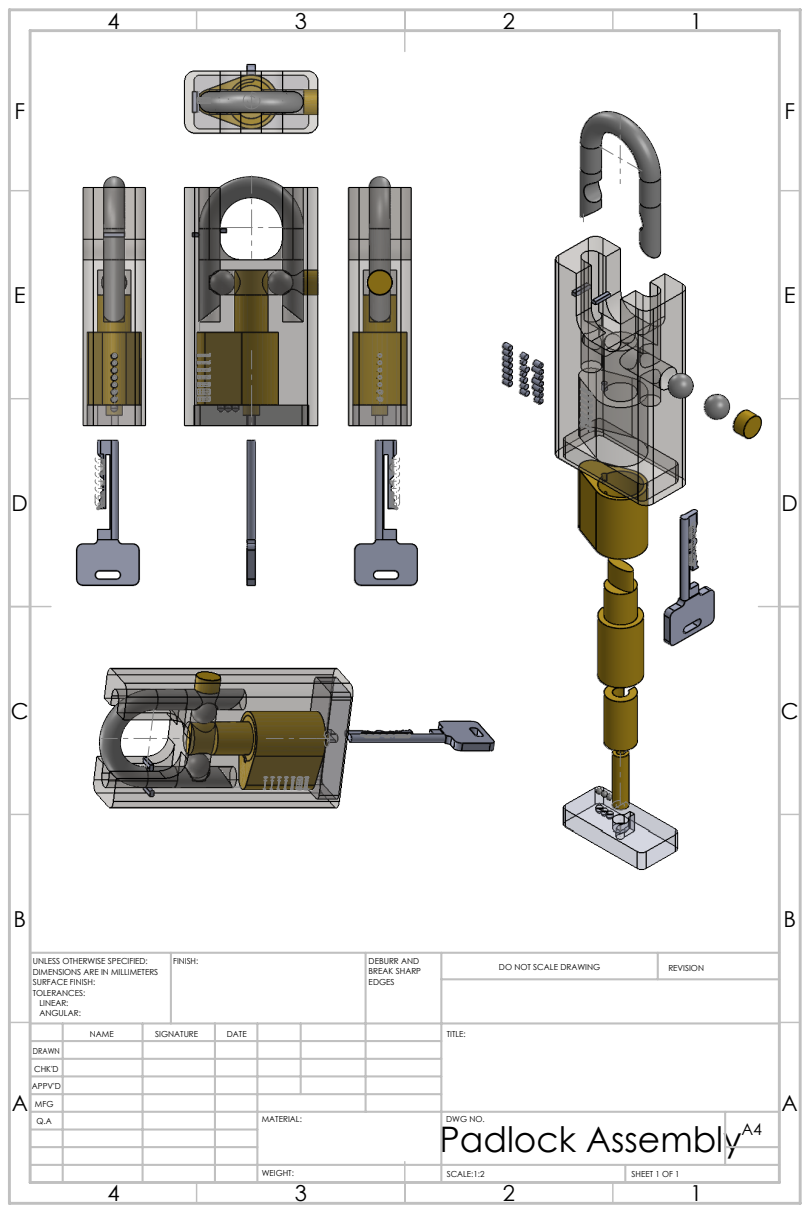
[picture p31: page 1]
FINISH:; DEBURR AND; BREAK SHARP; DO NOT SCALE DRAWING; REVISION; SCALE:1:2; SHEET 1 OF 1

UNLESS OTHERWISE SPECIFIED:
DIMENSIONS ARE IN MILLIMETERS
SURFACE FINISH:
TOLERANCES:
LINEAR:
ANGULAR:

NAME | SIGNATURE | DATE | | | | TITLE:

DRAWN
CHK'D
APPV'D
MFG
Q.A | | | | MATERIAL: | DWG NO. Padlock Assembly | A4
